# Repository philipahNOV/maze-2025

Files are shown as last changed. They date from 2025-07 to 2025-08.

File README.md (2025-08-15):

# Autonomous Maze Solver - NOV 2025

This project is an autonomous maze-solving system that uses computer vision and robotics to guide a steel ball through physical mazes. The system tilts a maze board with two motors to navigate the ball from start to goal while avoiding holes and obstacles.

The core architecture consists of three main devices: a Jetson Orin Nano for computer vision and control logic, a Raspberry Pi for the human-machine interface, and an Arduino for motor control. A ZED 2i stereo camera mounted above the maze provides real-time ball tracking using a TensorRT-optimized YOLOv8 model. The system calculates optimal paths with A* pathfinding and executes precise movements through PID control.

Users can choose between autonomous mode where the system solves the maze automatically, manual mode for joystick control with competitive timing, and human vs AI mode for head-to-head competition. A local leaderboard tracks the fastest completion times across different maze configurations.

Most system parameters are configured through `config.yaml`, making it easy to adapt to different maze layouts, adjust control parameters, and modify tracking settings without code changes.

---

## Table of Contents

- [System Overview](#system-overview)  
- [Physical Setup](#physical-setup)
- [Setup & Configuration](#setup--configuration)
  - [Login Information](#login--information)
  - [Dependencies](#dependencies)
- [Control System](#control-system)
  - [System Components](#system-components)
  - [Control Execution Flow](#control-execution-flow)
  - [Controller Configuration](#controller-configuration)
  - [Path Execution](#path-execution)
  - [Horizontal Calibration](#horizontal-calibration)
  - [MQTT Command Integration](#mqtt-command-integration)
  - [Troubleshooting](#troubleshooting)
  - [Tuning Tips](#tuning-tips)
  - [Electrical Setup](#electrical-setup)
- [MQTT Communication](#mqtt-communication)
  - [Overview](#overview)
  - [Topic Structure](#topic-structure)
  - [Handshake Protocol](#handshake-protocol)
  - [Jetson MQTT Client](#jetson-mqtt-client)
  - [Pi MQTT Client](#pi-mqtt-client)
  - [MQTT Troubleshooting](#mqtt-troubleshooting)
- [Ball Detection](#ball-detection)
  - [System Architecture](#ball-detection-architecture)
  - [Camera Acquisition](#camera-acquisition)
  - [TensorRT YOLO Inference](#tensorrt-yolo-inference)
  - [Ball Tracking](#ball-tracking)
  - [Tracker Service](#tracker-service)
  - [Detection Troubleshooting](#detection-troubleshooting)
- [A* Pathfinding](#a-pathfinding)
  - [A* Algorithm with Repulsion Field](#a-algorithm-with-repulsion-field)
  - [Binary Mask Preprocessing](#binary-mask-preprocessing)
  - [Waypoint Sampling](#waypoint-sampling)
  - [Path Drawing](#path-drawing)
  - [Path Memory Caching](#path-memory-caching)
  - [Nearest Walkable Point](#nearest-walkable-point)
  - [Pathfinding Troubleshooting](#pathfinding-troubleshooting)
- [Authors](#authors)

---

## System Overview

### Core Architecture
- **Jetson Orin Nano**: Primary control unit running TensorRT-optimized YOLOv8 inference, A* pathfinding, and PID control logic
- **Raspberry Pi**: Touchscreen HMI providing user interaction, mode selection, and real-time system status
- **Arduino Mega**: Motor controller executing precise tilt commands via dual-axis PID control
- **ZED 2i Camera**: Stereo camera providing real-time ball position tracking and maze orientation detection

### Software Components
- **Ball Detection**: TensorRT-accelerated YOLOv8 model with boundary validation and position smoothing
- **Path Planning**: A* algorithm with repulsion fields and optimized waypoint sampling
- **Control System**: PID-based position control with adaptive lookahead and error correction
- **Communication**: MQTT-based messaging between all system components
- **User Interface**: Multi-mode touchscreen interface with competitive leaderboards

### Operating Modes
- **Navigation Mode**: Automatic maze solving with real-time path visualization
- **Practice Mode**: Manual joystick control for practicing with a joystick
- **Play Alone**: Timed single-player challenges with leaderboard integration
- **Human vs Robot**: Competitive mode alternating between human and robot turns
- **Admin Tools**: Calibration, and access to shutdown and other tools

---

## Physical Setup

### Transport Configuration
Before operation, disconnect the transport rod by unscrewing with a 3mm hex key, then reinstall the screw at the bottom position.

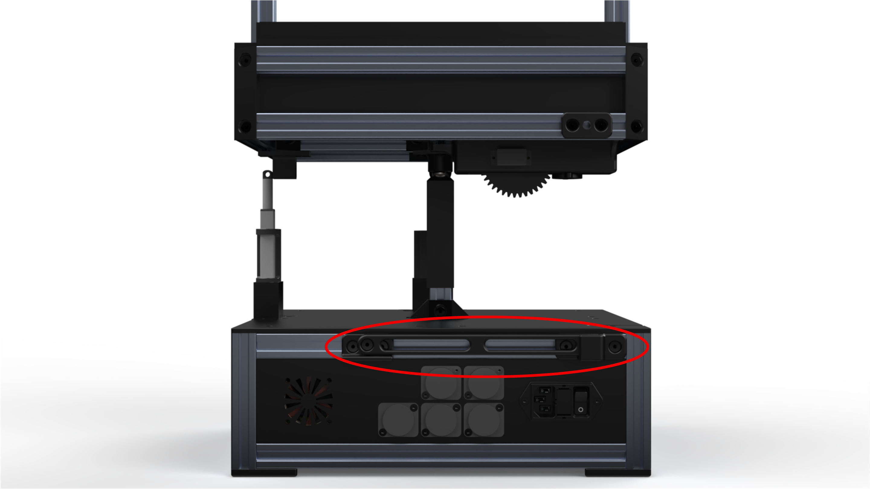
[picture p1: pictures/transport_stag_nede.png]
Transport Rod Up


For transportation, move the transport rod to the upper position to secure the platform.

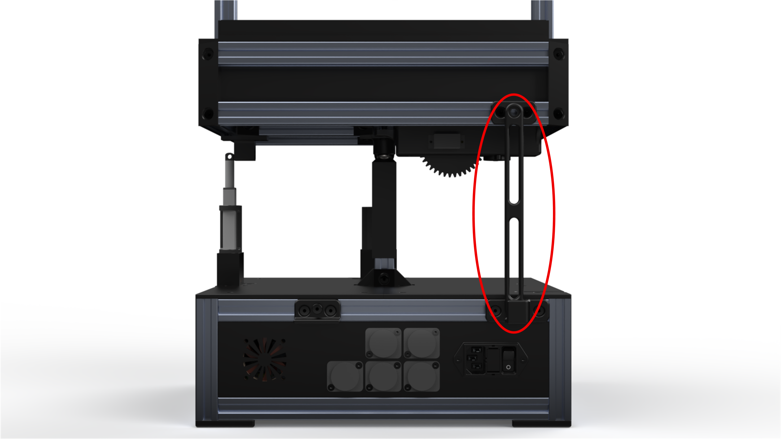
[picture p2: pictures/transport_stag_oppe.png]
Transport Rod Down


### Access Panels
Use a 2mm hex key to remove the electronics panel covers for maintenance access.

### Camera Positioning
Mount the ZED 2i camera directly above the maze center with clear line-of-sight to the entire playing surface.

---

## Setup & Configuration

### Login Information

**Raspberry Pi:**
- Username: raspberrypi
- Password: raspberry

**Jetson:**
- Username: student
- Password: student

### Dependencies

Install all required packages via requirements file:

```bash
pip install -r requirements.txt
```
---

## Flow of the FSM

The system operates through a well-defined state machine `finite_state_machine.py` with the following states:

### BOOTING
Initial state. Transitions to `MAIN_SCREEN` after the Raspberry Pi and Jetson perform a MQTT handshake.

### MAIN_SCREEN
Functions as a home-screen. May branch into several states.

### ADMIN_TOOLS
Requires a code to enter. From here, the admin can calibrate, clear leaderboards and path cache, restart, reboot or shutdown the robot.

### INFO_SCREEN
Displays information about the project.

### LOCATING
Transitioned into from `MAIN_SCREEN` when autonomous solving is chosen. Starts tracker and other threads required to locate the ball. When the ball is found, the state transitions to `CUSTOM_PATH`. 

### CUSTOM_PATH
In this state/screen, the user can choose a path goal by touching an image of the maze. By pressing 'Calculate path', finding a path will be attempted. If a path is found, start-buttons are enabled. The user can choose 'safe-control' or 'fast-control', which are two modes of the controller. When one of the buttons is pressed, the state transitions into `CONTROLLING`

### CONTROLLING
In this state, the control loop is running, letting the robot autonomously balance the ball through the maze. On the screen, a large live camera feed of the maze is displayed for the user to examin while executing. 

### HUMAN_CONTROLLER
Transitioned into from `MAIN_SCREEN` if the user chooses 'Game modes'. The main property of this state and states branching from it, is that the user may control the maze using and Xbox controller.

### PRACTICE
Playground for the user to attempt the maze without being able to loose and without being timed by a stop-watch.

### PLAYALONE
Start of the sequence of states that let the player attempt the maze while having their time recorded and, if succeeding, added to the leaderboard. In this state, the user may enter their name on the screen. Transitions into `PLAYALONE_START` when the user confirms their name

### PLAYALONE_START
In this state, the ball is continuously tracked. If the ball is located withing the elevator, the user may start their attempt. After pressing start, the user attempt is began, letting the user control the ball using the Xbox controller. If the ball falls through a hole, the state transitions into `PLAYALONE_FAILED`. If the ball reaches the goal, the state transitions into `PLAYALONE VICTORY`.

### PLAYALONE_FAILED
State where the user may either exit from the game mode, or choose to try again, returning to `PLAYALONE_START`

### PLAYALONE_VICTORY
The users maze solving time is saved. Their rank is computed by comparing the time to the leaderboard of the corresponding maze. The maze type (easy or hard) is automatically determined by the camera. The users time is added to the leaderboard.

### LEADERBOARD
Transitioned into using the corresponding button in either `HUMAN_CONTROLLER` or `PLAYALONE_VICTORY`. Displays the leaderboards of the easy and hard maze. The user may use a button to swap between the two displays.

### PLAYVSAI
Start of the sequence for the game mode 'Human vs Robot'. In this state, the user may choose a goal by touching an image of the maze. Then the user may press 'Start robot'.

### PLAYVSAI_PID
Transitioned into when the user presses 'Start robot' in `PLAYVSAI`. The robot computes a path to the goal, and attempts to balance the ball through it. If success, the time is saved.

### PLAYVSAI_HUMAN
Transitioned into after the robot has either failed or succeeded in `PLAYVSAI_PID`. The user may press 'Start turn' and then control the ball through the maze using the xBox controller. If success, the time is saved. The times of the robot and the user are compared, and the winner is determined. 

### **Sate transition logic**
Each state handles specific commands and maintains system integrity:
- **Back Commands**: Clean state transitions with resource cleanup
- **Error Handling**: Automatic fallback to safe states on failures
- **Resource Management**: Thread lifecycle and hardware control coordination

### **MQTT Command integration**

The control system integrates tightly with MQTT communication for coordinated operation:

**Command Processing**: The finite state machine subscribes to `jetson/command` topic and processes:
- Mode transitions (Practice, PlayAlone, Navigate, etc.)
- Game controls (StartGame, Retry, Back)
- System commands (Locate, AdminTools, Disco)

**Status Broadcasting**: Control states are published to relevant topics:
- `pi/command`: UI state updates and game results
- `pi/tracking_status`: Ball detection status and game events
- `arduino/speed`: Real-time motor control commands

## Control System

### System Components

The control system integrates multiple subsystems through a centralized finite state machine:

**Position Controller** (`position_controller.py`): 
- `posControl`: PID-based control system computing tilt angles in both X and Y axis required for the ball to reach the target waypoint.
- `axisControl`: P-controller that takes in reference tilt angles from the position controller, computes motor velocities, and sends the velocities to the Arduino

**Arduino Connection** (`arduino_connection.py`): Serial communication interface handling motor commands, elevator control, and system status feedback.

**Joystick Controller**: Manual control interface for practice mode and human vs AI gameplay.

### Controller Configuration

The PID controller accepts configuration through `config.yaml`:

```yaml
position_controller_normal:
    feedforward_t: 7.8
    kd_x: 0.000085
    kd_y: 0.000085
    ki_x: 0.0004
    ki_y: 0.0004
    kp_x: 0.00004
    kp_y: 0.00004
    position_tolerance: 25
    velocity_tolerance: 20
  position_smoothing_alpha: 0.1
  stuck_time_threshold: 0.5
  stuck_unstuck_hold_time: 0.2
  stuck_upper_position_threshold: 70
  stuck_velocity_threshold: 30
  stuck_wiggle_amplitude: 0.4
  stuck_wiggle_frequency: 20
  velocity_smoothing_alpha: 0.99
  wiggle_direction_bias: 0.007
```

**Key Parameters:**
- **feedforward_t**: Tuning parameter for feedforward. Increasing this reduces the responsiveness of the system. Decreasing may lead to fast but unstable responses.
- **kp**: Proportional gain. Increase to punish position error deviations.
- **ki**: Integral gain. Increase to punish position error deviations over time. Prevents steady-state errors.
- **kd**: Derivative gain. Increase for more damping. Increase to punish large velocities and to 'break' when approaching waypoints.
- **position_tolerance**: Acceptance radius for waypoint navigation.

### Path Execution

Path execution occurs in the `run_controller_main.main()` function with the following sequence:

1. **Path Validation**: Verify path waypoints are within maze boundaries
2. **Target Assignment**: Set initial target to first path waypoint
3. **Position Control Loop**:
   - Get current ball position from tracking service
   - Calculate PID control output for X/Y axes
   - Apply velocity limits and send motor commands
   - Check target proximity and advance to next waypoint
4. **Completion Detection**: Monitor goal proximity and handle success/failure states

### Path-following scheme
The controller may use one of two path-following schemes. Both schemes have advantages and dissadvantages, and the user may choose what scheme to use when starting the control execution after path-finding.
The member variable `lookahead` in `position_controller.py` can be set to `True` or `False` corresponding to waypoint navigation and pure pursuit respectively. This should be set before starting `run_controller_main.py`.

**Waypoint Navigation**

*In the HMI, this is referred to as "Safe Control"*
- Setpoint control toward the next waypoint
- Advances waypoint when the ball is within an acceptance radius
- Uses dwell/advance logic at each waypoint. This ensures the ball rests at waypoints and helps prevent prematurely turning around corners.
- Timeout based waypoint reverting. When a certain amount of time passes with no waypoint advancements, the target waypoint is reverted to the previous in the path.
- Pros:
    - Accurately controls to each waypoint
    - Ball velocity stays controllable
- Cons:
    - The scheme is optimal when the path consists of few waypoints. This large reduction with waypoint sampling may lead to important waypoints being removed, resulting in a bad path.
    - Slow. Stops at every waypoint.
    - Low velocities may result in the ball stopping just before a waypoint, then advancing. This leads to cutting of turns. This is attempted prevented using dwell/advance.

**Pure Pursuit**

*In the HMI, this is referred to as "Fast Control"*
- Projects the ball onto the nearest segment between two waypoints. Then walks along the path from the projected point a total distance of `lookahead distance`. The resulting point is chosen as the target reference for position control.
- The projection is continuous, resulting in a smoother path trajectory.
- Pros:
    - Continuous path following
    - Fast control due to not stopping at waypoints
    - Smooth path/turns
    - Natural ball movement
    - Does not rely on optimal waypoint sampling
- Cons:
    - Smaller reduction of waypoints through sampling. This results in a more computaionally expensive control loop.
    - Cuts turns due to the lookahead.
    - Velocity may build up enough to become difficult to stop quickly using damping.

### Horizontal Calibration

The system includes automatic horizontal calibration to establish a neutral maze position.
Calibration occurs automatically during state transitions and can be manually triggered through the admin interface.

### Tuning Tips

- Use current values as a base line
- More responsiveness -> Increase `feedforward_t`
- Smaller max velocities -> Increase `k_d`
- More accurately stopping at waypoints -> Increase `k_d`
- Prevent ball from getting stuck close to waypoints -> Increase `k_i`
- Improve path accuracy (waypoint navigation) -> Decrease `position_tolerance`
    - Consequence: Results in ball stopping more often and struggling to approach waypoint.
- Improve path accuracy (pure pursuit) -> Decrease `lookahead_distance`
    - Consequence: Reacts more slowly to path turns. Less predictive behaviour.

## Electrical Setup

This subsystem delivers power, feedback, actuation and data links between Jetson, Raspberry Pi, Arduino, motors and the user interface.

### Power Architecture
- Primary PSU:
    - Mean Well 85 W dual-output (5 V & 12 V)
- 5 V rail:
    - Raspberry Pi 5
    - LCD touch display
    - Elevator servo
    - LEDs
- 12 V rail:
    - NVIDIA Jetson Orin Nano
    - Motor controller
    - Enclosure cooling fan
- Arduino Mega:
    - Powered via USB from Jetson

### Arduino Interfaces
- 5 V out (Arduino) → Positive reference for actuators potentiometers
- Position feedback (linear actuator pots):
  - Motor 1: A4
  - Motor 2: A3
  - Approximate ADC span: ~2 (fully retracted) to ~1018 at 50 mm extension
- Motor PWM (direction-specific lines):
  - Motor 1 Up: D9
  - Motor 1 Down: D10
  - Motor 2 Up: D11
  - Motor 2 Down: D12
  (Only one direction pin per motor should be active at a time)
- Elevator servo: D5
- LEDs: D7

### Communication Wiring
- Jetson ↔ Arduino: USB serial (motor commands, servo, LEDs)
- Jetson ↔ Raspberry Pi: Ethernet (primary), MQTT over Wi‑Fi as fallback
- Arduino ↔ Motor Controller: PWM (D9–D12) + analog feedback (A4, A3)
- Touch screen (video): HDMI via pass‑through (switchable Pi / Jetson)
- Touch screen (touch interface): USB‑A (normally to Pi, movable to Jetson)

### Pass-Through Panel (Rear)
External I/O without opening the enclosure:
- 2 × USB‑A
- 2 × HDMI
- 1 × USB‑C (5 V power out)

Panel mapping:
- Lower USB‑A + lower HDMI → Raspberry Pi 5
- Lower USB‑C → 5 V (screen power)
- Upper USB‑A + upper HDMI → Jetson Orin Nano

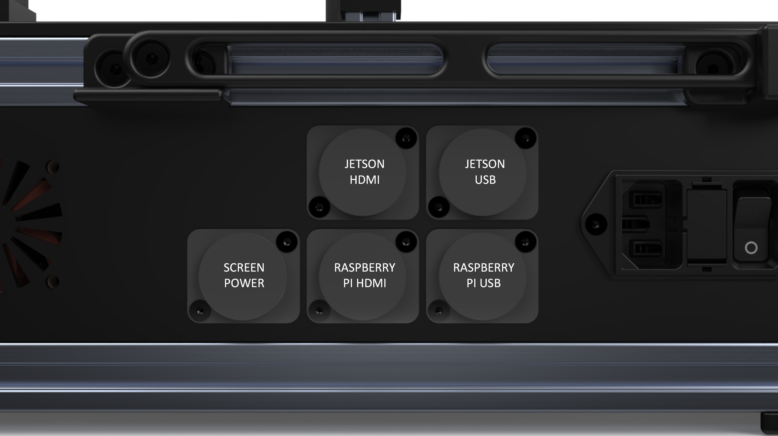
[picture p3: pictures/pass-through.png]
Pass-through Photo


### Touch Screen Usage
- Power: USB‑C cable
- Touch: USB‑A cable
- Normal mode: HDMI + USB‑A routed to Raspberry Pi
- Switch to Jetson: Move HDMI (and optionally touch USB) to Jetson-linked pass‑through ports

### Electrical Schematic
Schematic

### Fuses
- Power entry module: 3.15 A ceramic cartridge
- Each motor: 2 A glass cartridge
- Spares: Both types stored in the transport box

---

## MQTT Communication

### Overview

The system uses MQTT as the primary communication protocol between the Jetson control unit and Raspberry Pi interface. This lightweight publish-subscribe protocol gives a reliable message delivery with low latency.

Raspberry Pi IP: `192.168.1.2`

Jetson IP: `192.168.1.3`

The broker runs locally on the Jetson device.

### Topic Structure

The topic hierarchy follows a device-based naming convention for clear message routing:

#### **Jetson Publishes:**
- `handshake/response`: Handshake response to Pi.
- `pi/command`: General commands.
- `pi/camera`: Camera feed.
- `pi/info`: General information flow from Jetson to Pi.
- `pi/tracking_status`: Information about wether the tracker is started and wether or not the ball is found.
- `pi/leaderboard_data`: Sending of leaderboard data. 

#### **Pi publishes:**
- `hadshake/request`: Initiate handshake process.
- `jetson/command`: General commands to transition states in the FSM.
- `jetson/player_name`: Information about player name when using joystick.

### Handshake Protocol

Device initialization follows a structured handshake sequence to ensure reliable connection establishment:

1. **Pi Startup**: Publishes connection request to `jetson/handshake`
2. **Jetson Response**: Acknowledges connection and sends initial state
3. **State Synchronization**: Exchange current system mode and configuration
4. **Heartbeat Establishment**: Begin periodic status updates

### Jetson MQTT Client

The Jetson MQTT client (`MQTTClientJetson`) manages all communication from the control system:

```python
class MQTTClientJetson(threading.Thread):
    def __init__(self, arduino_connection: ArduinoConnection = None, fsm = None, broker_address="192.168.1.3", port=1883):
        super().__init__()
        self.client = mqtt.Client(mqtt.CallbackAPIVersion.VERSION2)  # type: ignore
        self.client.on_connect = self.on_connect
        self.client.on_message = self.on_message
        self.client.on_disconnect = self.on_disconnect

    def on_message(self, client, userdata, msg):
        payload = msg.payload.decode()
        topic = msg.topic
        print(f"Message received on topic '{topic}': {payload}")

        if topic == "handshake/request":
            if payload == "pi":
                self.client.publish("handshake/response", "ack", qos=1)
                self.client.publish("pi/command", "booted", qos=1)
                self.handshake_complete = True
```
### Pi MQTT Client

The Pi MQTT client handles the touchscreen interface and user interaction:

```python
class MQTTClientPi(threading.Thread):
    def __init__(self, broker_address='192.168.1.3', port=1883):
        super().__init__()
        self.client = mqtt.Client(mqtt.CallbackAPIVersion.VERSION2)
        self.client.on_connect = self.on_connect
        self.client.on_message = self.on_message
        
    def on_message(self, client, userdata, msg):
        if msg.topic == "pi/command":
            payload = msg.payload.decode()
            if payload.startswith("playalone_success:"):
                duration = payload.split(":")[1]
                rank = payload.split(":")[2]
                if self.app and hasattr(self.app, 'frames'):
```

### MQTT Troubleshooting

**Connection Issues:**
- Verify broker is running: `sudo systemctl status mosquitto`
- Check connectivity between devices
- Monitor broker logs: `sudo tail -f /var/log/mosquitto/mosquitto.log`

---

## Ball Detection

### System Architecture

The ball detection system uses a TensorRT-optimized YOLOv8 model for robust real-time ball tracking. The detection pipeline operates at 50 FPS with the following components:
- **Camera Manager**: ZED 2i stereo camera interface with hardware-accelerated frame capture
- **YOLO Model**: TensorRT-optimized object detection with CUDA context management
- **Ball Tracker**: Producer-consumer threading with boundary validation and position smoothing
- **Tracker Service**: High-level coordination and state management

### Camera Acquisition

The `CameraManager` class handles ZED 2i camera initialization and frame acquisition:

```python
CLASS CameraManager:
    INIT():
        Create ZED camera object
        Mark as not initialized

    FUNCTION init_camera():
        IF already initialized:
            RETURN
        Create camera initialization parameters:
            - Resolution: HD720
            - FPS: 60
            - Depth mode: Neural
            - Units: Millimeters
        TRY to open ZED camera with parameters
        IF open fails:
            RAISE error "Camera failed to open"
        Mark as initialized

    FUNCTION grab_frame():
        Create empty image container
        IF ZED grab() succeeds:
            Retrieve LEFT view image into container
            Convert image to BGR format
            Convert BGR to RGB format
            RETURN (rgb_frame, bgr_frame)
        ELSE:
            RETURN (None, None)

    FUNCTION get_orientation():
        Create sensor data container
        IF retrieving sensor data fails:
            RETURN None
        Get IMU data from sensor data
        Create transform container
        Get orientation quaternion from IMU pose
        Round quaternion values to 3 decimal places
        Calculate:
            dir1 = ox + ow
            dir2 = oy - oz
        RETURN orientation vector [-dir2, dir1]

    FUNCTION close():
        IF camera is initialized:
            Close ZED camera
            Mark as not initialized
```

### TensorRT YOLO Inference

The `YOLOModel` class implements optimized inference with TensorRT acceleration:

```python
CLASS YOLOModel:
    INIT(model_path, input_shape, conf):
        Store input shape and confidence threshold
        Initialize variables and lock
        TRY:
            Initialize TensorRT engine (preferred)
            Set engine_type = "tensorrt"
        EXCEPT:
            Print warning and fall back to PyTorch
            Set engine_type = "pytorch"

    FUNCTION _init_tensorrt(model_path):
        Initialize CUDA context
        Create TensorRT runtime
        Load engine from file
        Create execution context
        Get input/output bindings and data types
        Allocate host and device memory
        Create CUDA stream

    FUNCTION _init_pytorch_fallback(model_path):
        Convert engine path to .pt file path
        Load YOLO model from PyTorch
        Detect available device (GPU/CPU)
        Set class names from model

    DESTRUCTOR:
        If CUDA context exists, pop it

    FUNCTION get_label(cls_id):
        RETURN class name from ID

    FUNCTION preprocess(image):
        Resize image to model input size
        Normalize pixel values to [0,1]
        Rearrange channels (CHW)
        Convert to float16
        Copy into host input buffer

    FUNCTION predict(image):
        IF engine_type == "tensorrt":
            RETURN _predict_tensorrt(image)
        ELSE:
            RETURN _predict_pytorch(image)

    FUNCTION _predict_tensorrt(image) [ensured CUDA context]:
        Store original image dimensions
        Preprocess image
        Copy input data to GPU
        Execute inference asynchronously
        Copy output data from GPU
        Synchronize stream
        Postprocess and return results

    FUNCTION _predict_pytorch(image):
        Run PyTorch YOLO inference
        Return the first result object

    FUNCTION postprocess(output):
        If output shape is invalid → return empty result
        Filter detections by confidence threshold
        Convert normalized coords to original image coords
        Run Non-Maximum Suppression (NMS)
        Select best detection
        RETURN Result object with Box data

    FUNCTION nms(boxes, scores, iou_threshold):
        Sort boxes by score (descending)
        Iteratively keep highest-scoring boxes that don't overlap too much
        RETURN kept box indices

    FUNCTION _empty_result():
        RETURN object with empty boxes list

    FUNCTION shutdown():
        Acquire lock
        If already shutdown → return
        Mark as shutdown
        Free GPU memory
        Delete TensorRT resources
        Pop CUDA context if still active
        Print shutdown complete

CLASS Box:
    INIT(x1, y1, x2, y2, conf, cls):
        Store coordinates in xyxy format
        Store confidence and class
        Compute xywh format

CLASS Result:
    INIT(boxes):
        Store list of Box objects
```

**Performance Benefits:**
- **Fast**: TensorRT optimization significantly reduces inference time
- **Memory**: Optimized memory allocation and reuse
- **Latency**: Predictable inference times for real-time control
- **Fallback**: Automatic PyTorch fallback if TensorRT unavailable

### Ball Tracking

The `BallTracker` class implements a producer-consumer pattern for continuous ball tracking:

```python
CLASS BallTracker:
    INIT(camera, tracking_config, model_path):
        Load YOLO model from model_path
        Store camera reference
        Set configuration parameters (or defaults)
        Initialize runtime variables:
            - running state
            - initialized state
            - frame queue (small size buffer)
            - latest BGR frame
            - current ball position
            - bounding box buffer
            - maze boundaries (top-left, top-right, bottom-left, bottom-right)
    
    FUNCTION is_point_in_maze(x, y):
        RETURN True if point is inside maze bounds
    
    FUNCTION producer_loop():
        WHILE running:
            Record start time
            Capture RGB and BGR frames from camera
            IF frames are valid:
                Add frames to queue
            Sleep to maintain ~60 FPS

    FUNCTION consumer_loop():
        WHILE running:
            IF no frames in queue:
                Short sleep
                CONTINUE
            Remove older frames so only latest remains
            Take most recent RGB and BGR frames
            Store latest BGR for later retrieval

            Run YOLO inference on RGB frame
            Clear current ball position

            Filter predicted boxes for label "ball" (max 1)
            FOR each detected ball:
                Compute center coordinates
                IF ball center is inside maze:
                    Save ball position
                    Normalize coordinates relative to frame size
                    Update bounding box buffer
                    BREAK (only first ball used)

            Sleep to maintain ~50 FPS

    FUNCTION start():
        Set running = True and initialized = True
        Start producer thread (frame grabbing)
        Start consumer thread (detection/tracking)

    FUNCTION stop():
        Set running = False
        Set initialized = False
        IF model has shutdown method:
            Call shutdown

    FUNCTION get_position():
        RETURN current ball position

    FUNCTION get_frame():
        RETURN latest BGR frame (if available)

    FUNCTION retrack():
        Reset ball position
```

**Key Features:**
- **Threading**: Separate detection thread prevents blocking the control loop
- **Boundary Validation**: Rejects detections outside valid maze area
- **Position Smoothing**: Exponential moving average reduces noise
- **Thread Safety**: Proper locking for concurrent position access

### Tracker Service

The `TrackerService` provides a high-level interface for the tracking system:

```python
CLASS TrackerService:
    INIT(model_path, tracking_config):
        Create CameraManager instance
        Initialize camera
        Set tracker to None
        Mark as not started
        Store model path
        Store tracking config (or default)

    FUNCTION start_tracker():
        IF already started:
            RETURN
        Create BallTracker instance (pass camera, config, model_path)
        Start BallTracker threads (producer & consumer)
        Mark as started

    FUNCTION stop_tracker():
        IF started:
            Stop BallTracker
            Mark as not started

    FUNCTION get_ball_position():
        IF started:
            RETURN ball position from tracker
        ELSE:
            RETURN None

    FUNCTION get_stable_frame():
        IF started:
            RETURN latest BGR frame from tracker
        ELSE:
            RETURN None

    FUNCTION get_orientation():
        RETURN orientation vector from camera IMU

    PROPERTY is_initialized:
        RETURN tracker.initialized if tracker exists, else False

    FUNCTION retrack():
        IF started AND tracker exists:
            Call retrack() on BallTracker
```

### Detection Troubleshooting

**Common Issues and Solutions:**

**Ball Detection Failures:**
- Check lighting conditions, even illumination without shadows is ideal
- Verify camera focus and positioning for clear ball visibility
- Check GPU memory usage as insufficient VRAM can cause inference failures

**Position Accuracy Problems:**
- Calibrate the maze
- Check camera mounting stability

---

## A* Pathfinding

### A* Algorithm with Repulsion Field

The pathfinding system uses an enhanced A* algorithm with repulsion fields to generate safe, efficient paths through the maze. Unlike standard A*, this implementation adds artificial potential fields around obstacles to create paths that maintain safe distances from walls and holes.

#### **Heuristic Function**
The heuristic uses Manhattan distance:

```python
FUNCTION heuristic(a, b):
    RETURN Manhattan distance between a and b
    # (Alternatively: Euclidean distance for fewer node expansions)
```

#### **Repulsion Map Generation**
Repulsion fields are precomputed using distance transforms, in order to not make the path hug the walls:

```python
FUNCTION compute_repulsion_cost(array, min_safe_dist):
    Compute distance transform of obstacle map
    Create mask marking cells >= min_safe_dist as walkable
    Find maximum distance value
    IF max distance is zero:
        RETURN ones array (no repulsion), mask
    ELSE:
        Compute repulsion cost as (1 - (dist / max_dist))^3
        RETURN repulsion cost map, mask
```

#### **Path Search Implementation**
The core A* search integrates repulsion costs:

```python
FUNCTION astar(array, start, goal, repulsion_weight):
    rows, cols = dimensions of array
    repulsion_map, walkable_mask = compute_repulsion_cost(array)

    Define neighbor offsets (up, down, left, right)

    Create min-heap for open set
    Push start node with f = g + h

    Initialize:
        came_from = empty dict
        g_score = array filled with infinity
        g_score[start] = 0
        in_open = set containing start
        closed = boolean array (all False)

    WHILE open_heap not empty:
        Pop node with lowest fscore
        Remove from in_open

        IF current node == goal:
            Reconstruct path by backtracking via came_from
            RETURN path (start → goal)

        Mark current as closed

        FOR each neighbor offset (dx, dy):
            nx, ny = current.x + dx, current.y + dy

            IF neighbor out of bounds → skip
            IF not walkable or already closed → skip

            move_cost = 1 + repulsion_weight * repulsion_map[nx, ny]
            tentative_g = cost_so_far + move_cost

            IF tentative_g < g_score[neighbor]:
                Update came_from[neighbor] = current
                g_score[neighbor] = tentative_g
                fscore = tentative_g + heuristic(neighbor, goal)
                IF neighbor not in in_open:
                    Push (fscore, tentative_g, neighbor) to heap
                    Add neighbor to in_open

    RETURN empty list (no path found)
```

### Binary Mask Preprocessing

High-quality binary masks separating clear areas for the ball and the walls/holes are important for reliable pathfinding:

#### **Dilation and CLAHE**
```python
FUNCTION dilate_mask(mask, kernel_size, iterations):
    Create kernel of ones (uint8) with given size
    RETURN result of morphological dilation on mask using kernel for given iterations

FUNCTION get_dynamic_threshold(image, target_brightness):
    Convert image to grayscale
    Compute current average brightness
    Calculate adjustment = target_brightness - current_brightness
    Adjust grayscale pixel values by this amount (clip to range 0–255)
    RETURN adjusted grayscale image

FUNCTION apply_clahe(gray):
    Create CLAHE object (contrast-limited adaptive histogram equalization)
    Apply CLAHE to grayscale image
    RETURN enhanced grayscale image
```

#### **Edge Removal and Morphology**
```python
FUNCTION create_binary_mask(gray):
    enhanced = apply_clahe(gray)
    base_mask = Otsu binary threshold on enhanced image
    cleaned = Morphological closing (kernel 5x5) on base_mask, 2 iterations

    edges = Canny edge detection on enhanced image (thresholds 100, 200)
    edges_dilated = Dilate edges with 3x3 kernel, 1 iteration
    edges_inv = Invert edges_dilated

    final_mask = Logical AND between cleaned mask and edges_inv
    final_mask = Morphological closing (kernel 7x7) on final_mask, 1 iteration

    RETURN final_mask
```

### Waypoint Sampling

The waypoint sampling system transforms raw A* paths into optimized trajectories suitable for physical ball control. The process combines multiple geometric algorithms to balance path smoothness, control accuracy, and computational efficiency.

#### **Theoretical Foundation**

The system uses a multi-stage optimization pipeline:

1. **Raw path densification**: Continuous coverage along path segments by adding intermediate points at regular intervals
2. **Direction change**: Identifies course changes requiring explicit waypoints for accurate navigation
3. **L-Pivot smoothing**: Inserts intermediate waypoints at corners to for 90 degrees turns
4. **Douglas-Peucker**: Reduces redundant waypoints while preserving path geometry within specified tolerance
5. **Statistical refinement**: Segment length analysis to maintain consistent waypoint spacing

#### **Implementation**

The sampling algorithm processes raw A* output through several transformation stages:

```python
FUNCTION sample_waypoints(path, mask):
    raw = [first point in path]
    y, x = first point
    FOR each (ty, tx) in remaining path points:
        dx = tx - x
        sx = 1 if tx > x else -1
        FOR xx from x+sx to tx (inclusive) step sx:
            IF mask[y][xx] is walkable:
                append (y, xx) to raw
        x = tx

        dy = ty - y
        sy = 1 if ty > y else -1
        FOR yy from y+sy to ty (inclusive) step sy:
            IF mask[yy][x] is walkable:
                append (yy, x) to raw
        y = ty

    pts = [raw[0]]
    FOR (prev, curr, nxt) sliding through raw:
        dir1 = vector from prev → curr
        dir2 = vector from curr → nxt
        IF direction changes:
            append curr to pts
    append last point of raw to pts

    full = [pts[0]]
    FOR (a, b, c) sliding through pts:
        IF straight in one axis but corner in next:
            Generate intermediate corner points:
                (a.y, c.x), (c.y, c.x)
            IF not duplicate AND clear_path from last full point to new point:
                append new point to full
        IF b not already last in full:
            append b
    Append last point of pts if missing

    seg_dists = distances between consecutive points in full
    mean_seg = average segment length
    eps = mean_seg * log(raw_length + 1)
    waypoints = Douglas-Peucker simplify(full, eps)

    IF at least two waypoints:
        Compute average and std deviation of segment lengths
        threshold = avg + std
        new_wps = [first waypoint]
        FOR each segment (a, b):
            IF length > threshold:
                mid = midpoint between a and b
                append mid
            append b
        waypoints = new_wps

    RETURN waypoints

```

#### **Douglas-Peucker Algorithm**

The system uses the Douglas-Peucker algorithm for path simplification:

```python
FUNCTION _douglas_peucker(pts, eps):
    IF fewer than 3 points:
        RETURN pts

    a = first point in pts
    b = last point in pts
    idx = 0
    dmax = 0.0

    FOR i from 1 to len(pts)-2:
        d = _perp_dist(pts[i], a, b)
        IF d > dmax:
            idx = i
            dmax = d

    IF dmax <= eps:
        RETURN [a, b]  # all points lie close to straight line

    left = _douglas_peucker(points from a to pts[idx], eps)
    right = _douglas_peucker(points from pts[idx] to b, eps)

    RETURN left[:-1] + right

FUNCTION _perp_dist(pt, a, b):
    y0, x0 = pt
    y1, x1 = a
    y2, x2 = b

    num = ABS((x1 - x0) * (y2 - y0) - (x2 - x0) * (y1 - y0))
    den = Euclidean distance between a and b (avoid division by zero)
    RETURN num / den

```

### Path Drawing

Visual path representation for debugging and user feedback:

```python
FUNCTION draw_path(image, waypoints, start, goal):
    out = copy of image

    IF image is grayscale (2D) or has 1 channel:
        Convert to BGR
    ELSE IF image has 4 channels (BGRA):
        Convert to BGR

    h, w = image height and width

    FOR each (x, y) in waypoints (if any):
        IF y within [0, h) AND x within [0, w):
            Draw filled circle at (x, y) with radius 4 and color (128, 0, 0)  # dark red

    IF start exists:
        Draw filled green circle (0, 255, 0) at (start col, start row), radius 5
    IF goal exists:
        Draw filled blue circle (255, 0, 0) at (goal col, goal row), radius 5

    RETURN out

```

### Path Memory Caching

Caching reduces computation for repeated queries, skipping the A* loading time:

```python
FUNCTION get_cached_path(start, goal):
    FOR each entry in self.paths:
        s = entry["start"]
        g = entry["goal"]
        path = entry["path"]
        IF start is within tolerance of s AND goal is within tolerance of g:
            RETURN path
    RETURN None

FUNCTION cache_path(start, goal, path):
    IF number of cached paths >= max_paths:
        Remove the oldest entry from self.paths

    Append to self.paths:
        {
            "start": start as list,
            "goal": goal as list,
            "path": each point in path as list
        }

    Call self.save_cache()
```

### Nearest Walkable Point

Handles cases where start/goal points are in invalid areas:

```python
FUNCTION find_nearest_walkable(mask, point, max_radius):
    y, x = point

    IF mask[y, x] != 0:
        RETURN point

    dist = DistanceTransform of mask (L2 metric, kernel size 5)

    min_val = infinity
    nearest = point
    h, w = mask dimensions

    FOR dy from -max_radius to max_radius:
        FOR dx from -max_radius to max_radius:
            ny = y + dy
            nx = x + dx

            IF ny, nx inside mask bounds AND mask[ny, nx] > 0:
                IF dist[ny, nx] < min_val:
                    min_val = dist[ny, nx]
                    nearest = (ny, nx)

    RETURN nearest
```

### Pathfinding Troubleshooting

#### **repulsion_weight**
Controls how strongly paths avoid obstacles:
- **Too Low (<5)**: Paths may pass too close to walls, risking collisions
- **Too High (>20)**: Paths become overly conservative and inefficient
- **Optimal Range**: 8-15 for most maze configurations

#### **min_safe_dist in repulsion**  
Minimum distance maintained from obstacles:
- **Too Small (<10 pixels)**: Insufficient safety margin for control errors
- **Too Large (>30 pixels)**: May make narrow passages impassable
- **Recommended**: 15-25 pixels based on ball size and control precision

---

## Authors

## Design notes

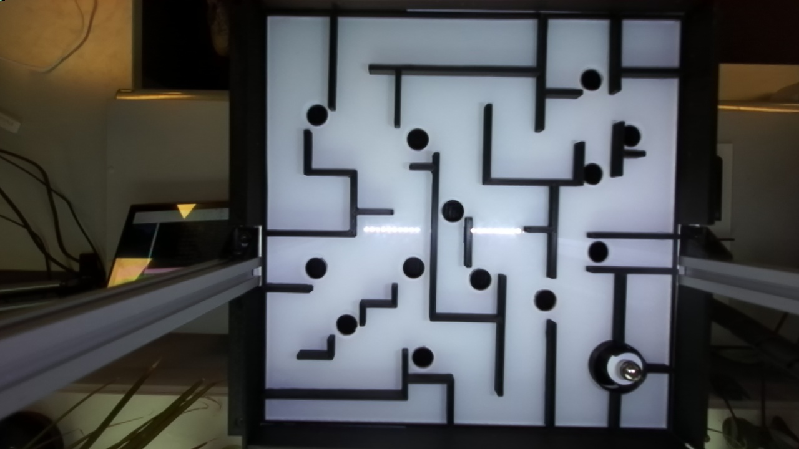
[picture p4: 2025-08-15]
jetson/src/MAZE_PICS/Hard.jpg

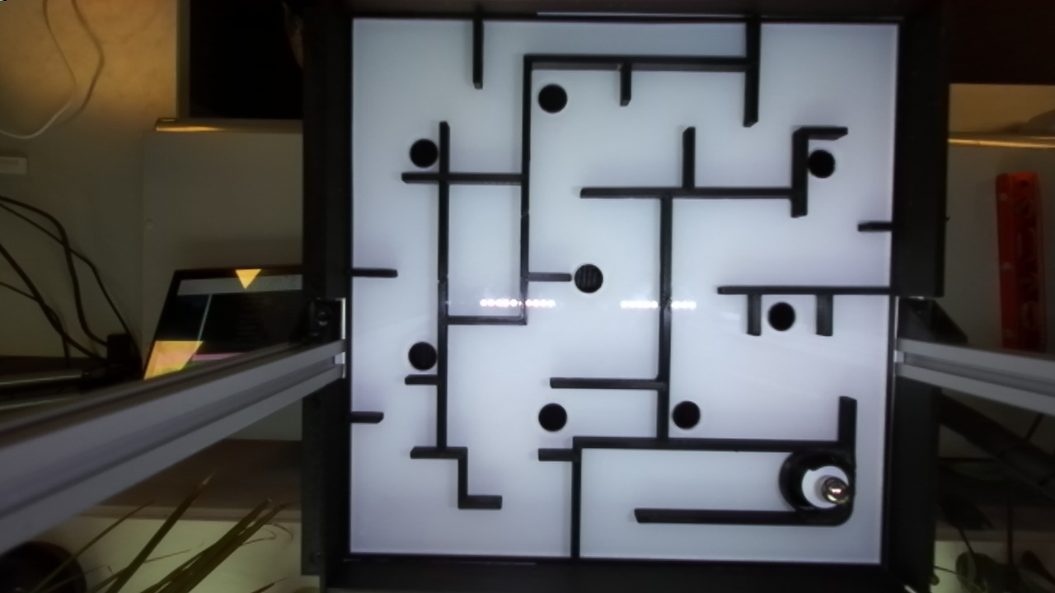
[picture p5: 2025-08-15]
jetson/src/MAZE_PICS/Easy.jpg

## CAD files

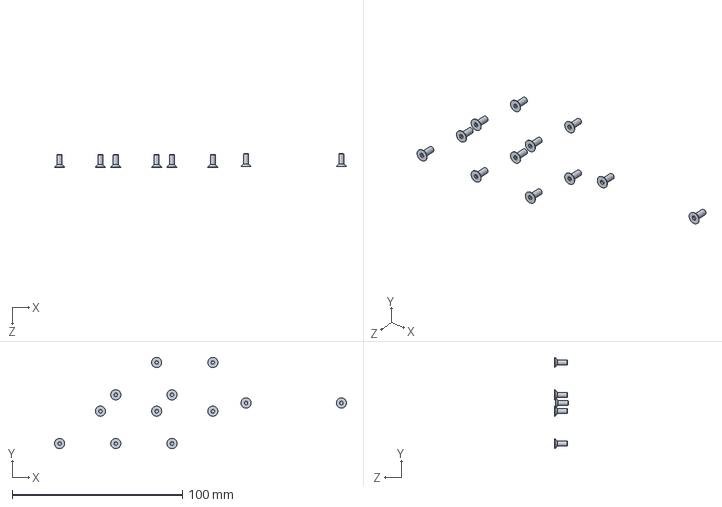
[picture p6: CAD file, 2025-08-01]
3d_modeler/sammensetning/vegger/vegg_bak_sammensetning.SLDASM
171.5 x 53.6 x 8.15 mm
skrue_m3x6 x 12

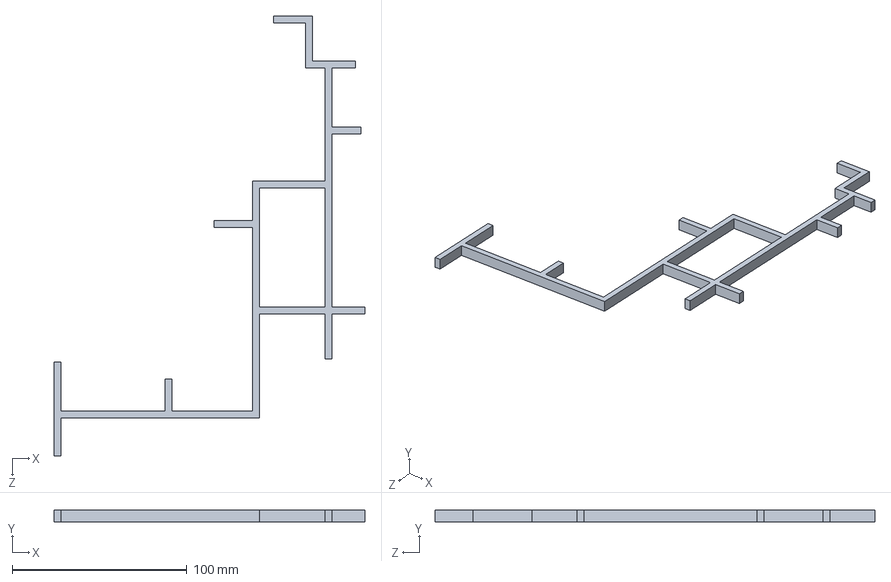
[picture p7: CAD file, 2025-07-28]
3d_modeler/labyrint/labyrint_lett/vegger_separat/vegg_4.SLDPRT
177.8 x 7.00 x 251.4 mm

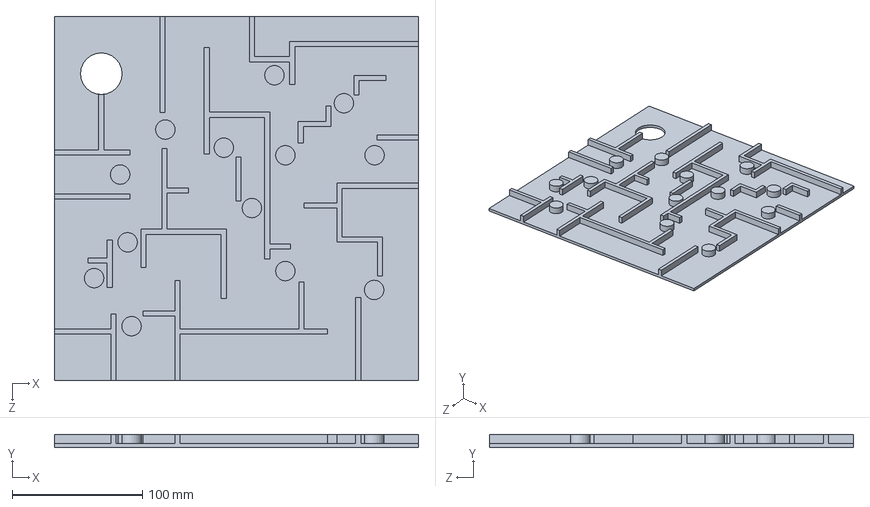
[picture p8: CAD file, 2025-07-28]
3d_modeler/labyrint/labyrint_mellom/labyrint_mellom.SLDPRT
280.0 x 10.0 x 280.0 mm

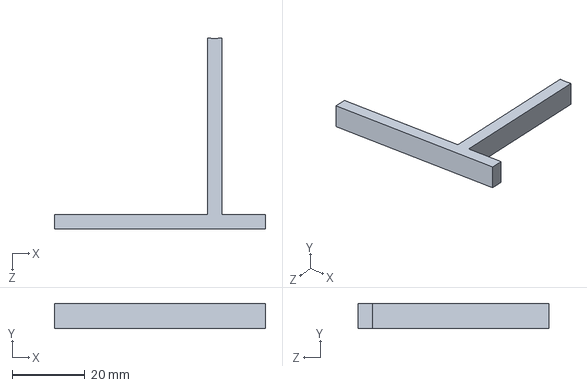
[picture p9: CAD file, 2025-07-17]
3d_modeler/labyrint/labyrint_mellom/vegger/vegg_2.SLDPRT
58.0 x 7.00 x 52.5 mm

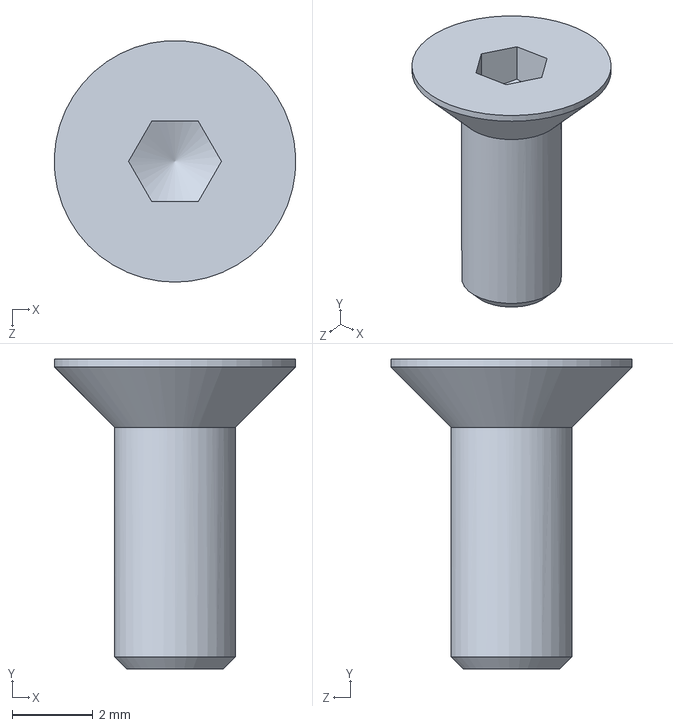
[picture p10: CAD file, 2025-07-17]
3d_modeler/sammensetning/aluminiumsprofiler/skrue_m3x6.SLDPRT
6.00 x 7.70 x 5.99 mm

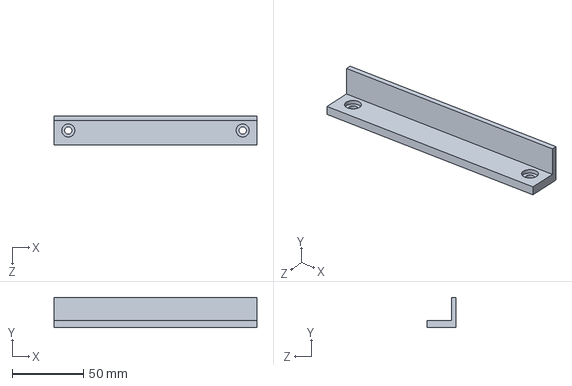
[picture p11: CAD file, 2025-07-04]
3d_modeler/sammensetning/bane_vegger/bane_vegg_142.SLDPRT
142.0 x 21.0 x 20.4 mm

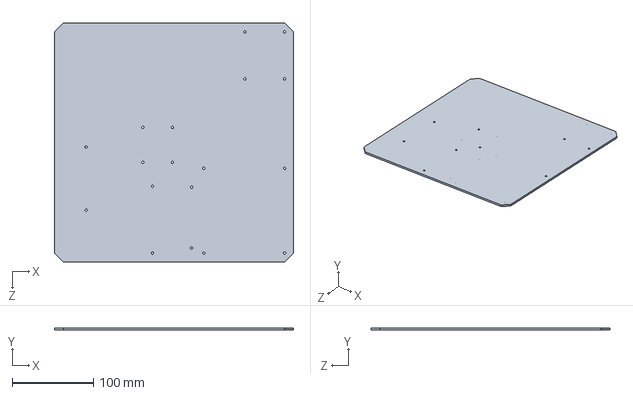
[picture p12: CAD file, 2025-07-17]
3d_modeler/sammensetning/komponenter/komponent_holder_plate.SLDPRT
295.0 x 3.00 x 295.0 mm

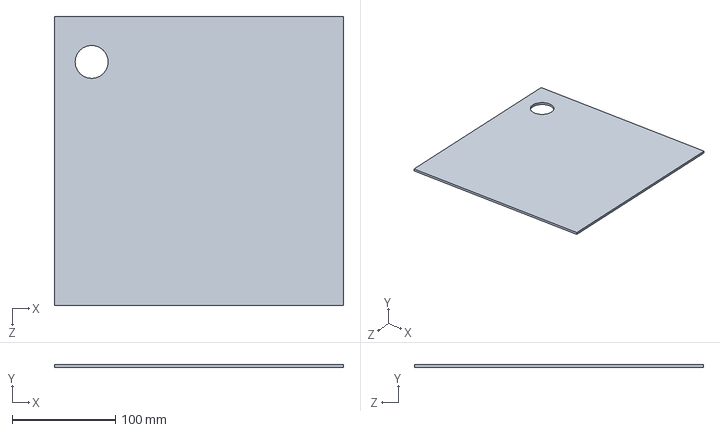
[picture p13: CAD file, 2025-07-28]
3d_modeler/sammensetning/labyrint_plate/labyrint_plate.SLDPRT
280.0 x 3.00 x 280.0 mm

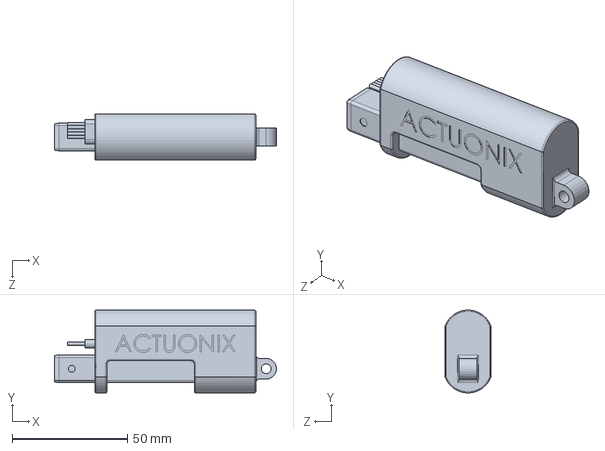
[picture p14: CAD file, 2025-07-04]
3d_modeler/sammensetning/motor/ACTUONIX-P16-50-64-12-P_HOUSING.SLDPRT
96.5 x 36.0 x 20.0 mm

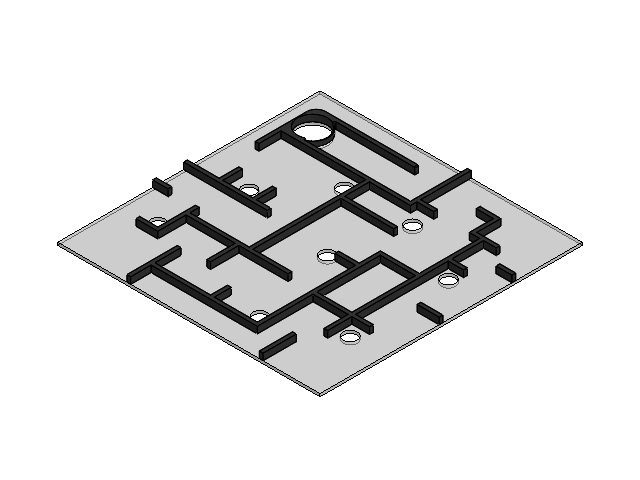
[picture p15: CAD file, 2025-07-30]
3d_modeler/labyrint/labyrint_lett/labyrint_lett.SLDASM
labyrint_lett_plate
labyrint_lett_vegger

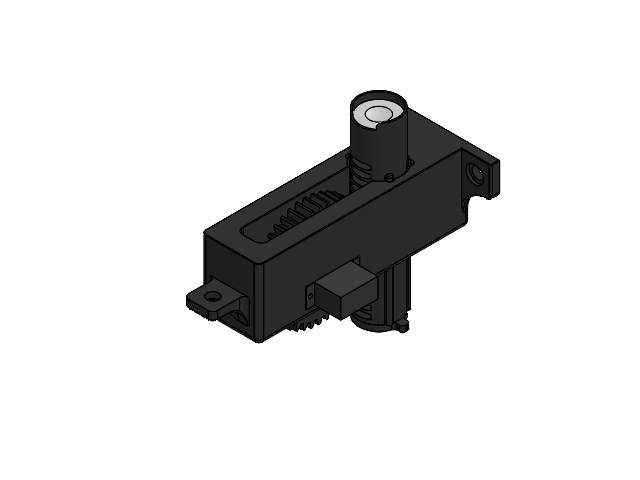
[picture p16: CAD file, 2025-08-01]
3d_modeler/sammensetning/ball_heis/heis.SLDASM
heis_holder
tannhjul
heis_stag
heis_stag_stopper
heis_stag_topp_inlegg
skrue_m3x6
servo_hus
servo_arm

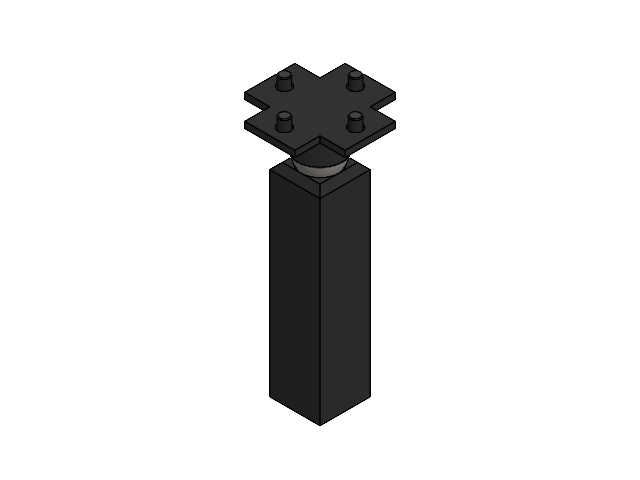
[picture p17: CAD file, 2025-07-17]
3d_modeler/sammensetning/kuleledd/kuleledd.SLDASM
kuleledd_nede
kule
kuleledd_oppe
skrue_m5x8 x 4

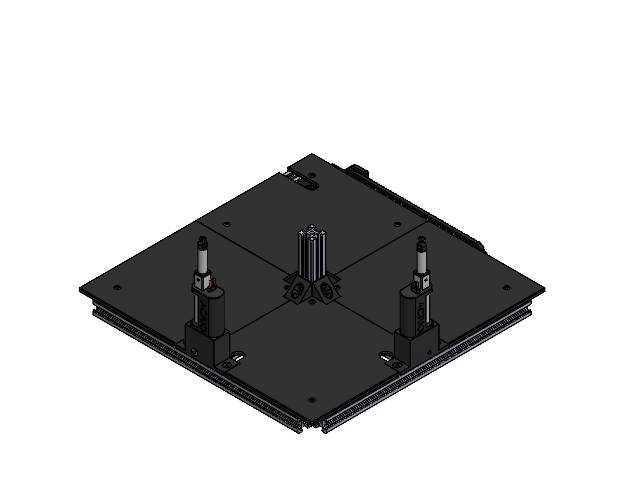
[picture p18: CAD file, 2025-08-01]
3d_modeler/sammensetning/midt_ramme.SLDASM
hjørne_kobling_midt x 16
20x20x285 x 5
20x20x132_5 x 2
20x20x70_5
hjørne_kobling x 4
motor_holder_nede x 2
ACTUONIX-P16-50-64-12-P_HOUSING x 2
ACTUONIX-P16-50-64-12-P_ROD x 2
topp_lokk_høyre_bak
topp_lokk_høyre_forann
topp_lokk_venstre_bak
topp_lokk_venstre_forann
transport_stag
transport_holder_nede
treplugg
transport_holder_nede_ende
skrue_m3x6 x 16
skrue_m5x8 x 49
socket countersunk head screw_iso x 2

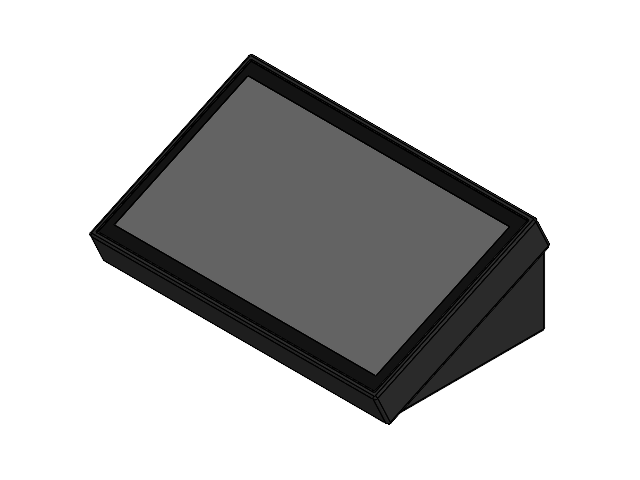
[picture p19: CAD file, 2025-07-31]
3d_modeler/skjerm_stativ/skjerm_stativ.SLDASM
skjerm_deksel
skjerm_bein_venstre
skjerm_bein_høyre
tapp x 2
10.1inch HDMI.stp
skrue_m3x6 x 4
spennings_avlaster

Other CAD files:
3d_modeler/sammensetning/ball_heis/heis_stag_med_stopper.SLDASM
3d_modeler/sammensetning/motor/ACTUONIX-P16-50-64-12-P_ASSEMBLY.SLDASM
3d_modeler/sammensetning/nedre_ramme.SLDASM
3d_modeler/sammensetning/ball_heis/servo.SLDASM
3d_modeler/labyrint/labyrint_lett/labyrint_lett_plate.SLDPRT
3d_modeler/labyrint/labyrint_lett/labyrint_lett_vegger.SLDPRT
3d_modeler/labyrint/labyrint_lett/vegger_separat/vegg_1.SLDPRT
3d_modeler/labyrint/labyrint_lett/vegger_separat/vegg_1_a.SLDPRT
3d_modeler/labyrint/labyrint_lett/vegger_separat/vegg_1_b.SLDPRT
3d_modeler/labyrint/labyrint_lett/vegger_separat/vegg_2.SLDPRT
3d_modeler/labyrint/labyrint_lett/vegger_separat/vegg_3.SLDPRT
3d_modeler/labyrint/labyrint_lett/vegger_separat/vegg_4_a.SLDPRT
3d_modeler/labyrint/labyrint_lett/vegger_separat/vegg_4_b.SLDPRT
3d_modeler/labyrint/labyrint_lett/vegger_separat/vegg_5.SLDPRT
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

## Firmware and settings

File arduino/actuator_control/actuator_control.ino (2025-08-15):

// Inkluderer nødvendige biblioteker
#include <Servo.h> // For servo kontroll
#include <Adafruit_NeoPixel.h> // For styring av NeoPixel LED

// Initialiserer variabler
// Navnerom for aktuatorene
namespace actuators {
    
    // Struct for pinnenummerene
    struct ActuatorData
    {
        const uint8_t pwm_up; // Pinne for PWM oppover
        const uint8_t pwm_down; // Pinne for PWM nedover
        const uint8_t pot_feedback; // Pinne for potensjometer
        float position; // Posisjon til aktuatoren (mm)
        int8_t distance_status; // Motor status. -1 er under nedre grense, 1 er over øvre grense
    };

    // Aktuator en
    ActuatorData actuator_1 = {9, 10, A4, 0, 0}; // PWM oppover = 9, PWM nedover = 10, Potensjometer = A4

    // Aktuator to
    ActuatorData actuator_2 = {11, 12, A3, 0, 0}; // PWM oppover = 11, PWM nedover = 12, Potensjometer = A3
}

namespace lift_servo {
    Servo lift; // Servo for heis
    const uint8_t servo_pin = 5; // Pinne for servo
    const uint8_t lift_down = 170; // Lav posisjon for heis
    const uint8_t lift_up = 20; // Høy posisjon for heis
    const uint8_t lift_stop = 90; // Stopp posisjon for heis
    unsigned long elevator_start_time = 0; // Tidspunkt for når heisen startet å kjøre
    bool elevator_running = false; // Variabel for å sjekke om heisen er aktiv
}

namespace led_strips {
    const uint8_t led_pin = 7; // Pinne for LED strip
    const uint16_t num_leds = 10; // Antall LED i stripen 
    Adafruit_NeoPixel strip = Adafruit_NeoPixel(num_leds, led_pin, NEO_GRB + NEO_KHZ800); // Initialiserer LED stripen
}

namespace serial_messages {
    // Enum for tilstander i programmet
    enum class State
    {
        IDLE, // Tilstand for å vente på kommandoer
        ELEVATOR, // Tilstand for å hente ball
        CONTROL, // Tilstand for å kontrollere aktuatorene
        SET_COLOR // Tilstand for å sette farge på LED stripen
    };

    State state = State::IDLE; // Initialiserer tilstanden til IDLE

    // Variabler for seriedata
    int16_t value_1 = 0; // Variabel for første verdi i seriedata
    int16_t value_2 = 0; // Variabel for andre verdi i seriedata
    int16_t value_3 = 0; // Variabel for tredje verdi i seriedata
    int16_t value_4 = 0; // Variabel for fjerde verdi i seriedata
}

// Navnerom for globale variabler
namespace {
    // Teller for hvor ofte grensen sjekkes for aktuatorene
    uint8_t limit_check_counter = 0;
}

// Initialiserer funksjoner
void stop_actuators(); // Funksjon for å stoppe aktuatorene
void actuator_position(); // Funksjon for posisjonen til aktuatoren
void actuator_limit_check(); // Funksjon for å sjekke om aktuatoren er over eller under ønsket maks eller min høyde
void move_speed(int16_t speed_actuator_1, int16_t speed_actuator_2); // Funksjon for å bevege begge aktuatorene med hastighetene i actuator_speeds
void elevator(int8_t elevator_dir); // Funksjon for å kontrollere heisen for å hente ball
void set_led_color(uint8_t r, uint8_t g, uint8_t b, int8_t led_number); // Funksjon for å sette fargen på LED stripen
void read_serial(); // Funksjon for å lese innkommende seriedata

void setup() {
    // Starter seriel kominikasjon
    Serial.begin(115200);

    // Initialiserer LED stripen
    led_strips::strip.begin(); // Starter LED stripen
    led_strips::strip.setBrightness(255); // Setter lysstyrken til stripen
    // Setter alle LED til hvit farge
    set_led_color(255, 255, 255, -1); // Setter fargen til hvit

    // Setter pin modusene
    // Aktuator en
    pinMode(actuators::actuator_1.pwm_up, OUTPUT); // Setter PWM pinne for aktuator en oppover
    pinMode(actuators::actuator_1.pwm_down, OUTPUT); // Setter PWM pinne for aktuator en nedover

    // Aktuator to
    pinMode(actuators::actuator_2.pwm_up, OUTPUT); // Setter PWM pinne for aktuator to oppover
    pinMode(actuators::actuator_2.pwm_down, OUTPUT); // Setter PWM pinne for aktuator to nedover

    // Setter analog pinnene til null for at motorene ikke bevege seg når programmet starter
    stop_actuators(); // Stopper aktuatorene
/*
    lift_servo::lift.attach(lift_servo::servo_pin);
    lift_servo::lift.write(0);
    delay(500);
    lift_servo::lift.detach();
    */
}

void loop() {
    read_serial(); // Motar data over seriel fra Jetson

    switch (serial_messages::state) // Sjekker hvilken tilstand programmet er i
    {
        case serial_messages::State::ELEVATOR: // Tilstand 0: Heis klar til å hente ball

            // Sjekk om heisen heisen står stille og om det er over 1s siden den ble kjørt sist
            if (lift_servo::elevator_running == false)
            {
                elevator(serial_messages::value_1); // Kjører heisen
            }
            else
            {
                // Gjør ingen ting
            }
            
            serial_messages::state = serial_messages::State::IDLE; // Går til neste tilstand
            break;
        case serial_messages::State::CONTROL: // Tilstand 1: Kontrollerer aktuatorene
            actuator_limit_check(); // Sjekker om aktuatorene er over eller under grensen og oppdaterer distance_status
            move_speed(serial_messages::value_1, serial_messages::value_2); // Setter motor hastighetene
            break;
        case serial_messages::State::SET_COLOR: // Tilstand 2: Setter farge på LED stripen
            set_led_color(serial_messages::value_1, serial_messages::value_2, serial_messages::value_3, serial_messages::value_4); // Setter fargen på LED stripen
            serial_messages::state = serial_messages::State::IDLE; // Går til neste tilstand
            break;
        default: // Standard tilstand: Ingen handling
            stop_actuators(); // Stopper aktuatorene
            break;
    }

    if (lift_servo::elevator_running == true && millis() - lift_servo::elevator_start_time >= 200)
    {
        elevator(0);
        lift_servo::elevator_running = false;
        
    }
}

void stop_actuators()
{
    // Funksjon for å stoppe aktuatorene
    // Aktuator en
    analogWrite(actuators::actuator_1.pwm_up, 0); // Setter PWM pinne for aktuator en oppover til 0
    analogWrite(actuators::actuator_1.pwm_down, 0); // Setter PWM pinne for aktuator en nedover til 0
    actuators::actuator_1.position = 0; // Nullstiller posisjonen til aktuator en

    // Aktuator to
    analogWrite(actuators::actuator_2.pwm_up, 0); // Setter PWM pinne for aktuator to oppover til 0
    analogWrite(actuators::actuator_2.pwm_down, 0); // Setter PWM pinne for aktuator to nedover til 0
    actuators::actuator_2.position = 0; // Nullstiller posisjonen til aktuator to
}

// Funksjon for å returnere posisjonen til aktuatoren
void actuator_position() // Tar inn en peker til potensjometer pinnen
{
    const float act_max_stroke{50.0}; // Maks slaglengde for aktuatorene (mm)
    const float adc_max_hight{1018.0}; // ADC verdien for maks lengde
    const float adc_min_hight{2.0}; // ADC verdi for minimum lengde

    // Kalkulerer distansen til aktuator en
    actuators::actuator_1.position = (float(analogRead(actuators::actuator_1.pot_feedback)) - adc_min_hight) * act_max_stroke / (adc_max_hight - adc_min_hight);
    // Kalkulerer distansen til aktuator to
    actuators::actuator_2.position = (float(analogRead(actuators::actuator_2.pot_feedback)) - adc_min_hight) * act_max_stroke / (adc_max_hight - adc_min_hight);
}

// Funksjon for å sjekke om aktuatorene er over eller under grensen
void actuator_limit_check()
{   
    const uint8_t limit_check_interval = 10; // Sjekk grenser kun hver 10. loop

    limit_check_counter++; // Øker telleren for hvor ofte grensen sjekkes
    if (limit_check_counter < limit_check_interval) // Sjekker ikke grensen for ofte
    {
        return; // Ikke sjekk grensen
    }
    else
    {
        limit_check_counter = 0; // Nullstiller telleren
    }

    const float act_max_stroke{50.0}; // Maks slaglengde for aktuatorene (mm)
    const float offset{3.0}; // Distansen fra toppen og bunden hvor aktuatorene ikke skal gå innenfor (mm)

    actuator_position(); // Leser inn posisjonen til aktuatorene

    // Sjekker aktuator en
    if (actuators::actuator_1.position >= act_max_stroke - offset) // Hvis aktuator en
    {
        actuators::actuator_1.distance_status = 1; // Setter status til 1 (for høyt)
    }
    else if (actuators::actuator_1.position <= offset) // Hvis aktuator en er for lavt
    {
        actuators::actuator_1.distance_status = -1; // Setter status til -1 (for lavt)
    }
    else // Hvis aktuator en er innenfor grensen
    {
        actuators::actuator_1.distance_status = 0; // Setter status til 0 (OK)
    }

    // Sjekker aktuator to
    if (actuators::actuator_2.position >= act_max_stroke - offset) // Hvis aktuator to er for høyt
    {
        actuators::actuator_2.distance_status = 1; // Setter status til 1 (for høyt)
    }
    else if (actuators::actuator_2.position <= offset) // Hvis aktuator to er for lavt
    {
        actuators::actuator_2.distance_status = -1; // Setter status til -1 (for lavt)
    }
    else // Hvis aktuator to er innenfor grensen
    {
        actuators::actuator_2.distance_status = 0; // Setter status til 0 (OK)
    }
}

// Funksjon for å sette hastighetene til aktuatorene basert på actuator_speeds
void move_speed(int16_t speed_actuator_1, int16_t speed_actuator_2)
{
    // Aktuator 1
    if (speed_actuator_1 > 0 && actuators::actuator_1.distance_status != 1) // Hvis aktuator en skal bevege seg oppover og ikke er for høyt
    {
        analogWrite(actuators::actuator_1.pwm_up, speed_actuator_1);
        analogWrite(actuators::actuator_1.pwm_down, 0);
    } 
    else if (speed_actuator_1 < 0 && actuators::actuator_1.distance_status != -1) // Hvis aktuator en skal bevege seg nedover og ikke er for lavt
    {
        analogWrite(actuators::actuator_1.pwm_up, 0);
        analogWrite(actuators::actuator_1.pwm_down, -speed_actuator_1); // - for å få riktig retning
    }
    else // Hvis aktuator en ikke skal bevege seg
    {
        analogWrite(actuators::actuator_1.pwm_up, 0);
        analogWrite(actuators::actuator_1.pwm_down, 0);
    }
    
    // Aktuator 2
    if (speed_actuator_2 > 0 && actuators::actuator_2.distance_status != 1) // Hvis aktuator to skal bevege seg oppover og ikke er for høyt
    {
        analogWrite(actuators::actuator_2.pwm_up, speed_actuator_2);
        analogWrite(actuators::actuator_2.pwm_down, 0);
    } 
    else if (speed_actuator_2 < 0 && actuators::actuator_2.distance_status != -1) // Hvis aktuator to skal bevege seg nedover og ikke er for lavt
    {
        analogWrite(actuators::actuator_2.pwm_up, 0);
        analogWrite(actuators::actuator_2.pwm_down, -speed_actuator_2); // - for å få riktig retning
    }
    else // Hvis aktuator to ikke skal bevege seg
    {
        analogWrite(actuators::actuator_2.pwm_up, 0);
        analogWrite(actuators::actuator_2.pwm_down, 0);
    }
}

void elevator(int8_t elevator_dir)
{
    if (lift_servo::lift.attached() == false && lift_servo::elevator_running == false)
    {
        lift_servo::lift.attach(lift_servo::servo_pin);
    }
    else if (lift_servo::lift.attached() == true && lift_servo::elevator_running == true)
    {
        lift_servo::lift.detach();
        return;
    }
    else
    {
        // Gjør ingenting
    }

    if (elevator_dir == -1 && lift_servo::lift.read() != lift_servo::lift_down)
    {
        lift_servo::lift.write(lift_servo::lift_down);
        lift_servo::elevator_start_time = millis();
        lift_servo::elevator_running = true;
    }
    else if (elevator_dir == 1 && lift_servo::lift.read() != lift_servo::lift_up)
    {
        lift_servo::lift.write(lift_servo::lift_up);
        lift_servo::elevator_start_time = millis();
        lift_servo::elevator_running = true;
    }
    else
    {
      lift_servo::lift.detach();
        // Gjør ingenting
    }
}


// Funksjon for å sette fargen på LED stripen
void set_led_color(uint8_t r, uint8_t g, uint8_t b, int8_t led_number) {

    // Setter alle LED til en spesifikk farge
    if (led_number == -1)
    {
        for (uint8_t i = 0; i < led_strips::num_leds; i++) {
        led_strips::strip.setPixelColor(i, led_strips::strip.Color(r, g, b)); // Setter fargen på hver LED
        }
    }
    // Setter en spesifikk LED til en spesifikk farge
    else if (led_number >= 0 && led_number < led_strips::num_leds)
    {
        led_strips::strip.setPixelColor(led_number, led_strips::strip.Color(r, g, b)); // Setter fargen på den spesifikke LED
    }
    else
    {
        Serial.println("Invalid LED number!"); // Skriver ut en feilmelding hvis led_number er utenfor gyldig område
        return; // Avslutter funksjonen tidlig
    }
    led_strips::strip.show(); // Oppdaterer stripen for å vise endringene
}

// Funksjon for å lese innkommende seriedata
void read_serial()
{
    // Leser innkommende seriedata fra Jetson
    if (Serial.available() <= 0)
    {
        return; // Hvis det ikke er noen data tilgjengelig, bare avslutt funksjonen.
    }

    // Nullstiller verdiene
    serial_messages::value_1 = 0; 
    serial_messages::value_2 = 0;
    serial_messages::value_3 = 0;
    serial_messages::value_4 = 0;

    char buffer[64]; // Buffer for å lagre innkommende data
    int len = Serial.readBytesUntil('\n', buffer, sizeof(buffer) - 1); // Leser data til linjeskift eller buffer er fullt

    // Legg til sjekk for å sikre at vi faktisk leste noe før vi parser
    if (len > 0)
    {
        buffer[len] = '\0'; // Null-terminerer strengen for sikkerhet
            
        int v1, v2, v3, v4, incoming_state;

        // Tell antall kommaer for å bestemme meldingstype raskt
        uint8_t comma_count = 0;
        for (int i = 0; i < len; i++)
        {
            if (buffer[i] == ',')
            {
                comma_count++;
            }
        }
        
        // Sjekk for den vanligste meldingen FØRST: CONTROL (2 hastigheter + state)
        if (comma_count == 2) // For CONTROL-meldinger (f.eks. "25,200,1")
        {
            if (sscanf(buffer, "%d,%d,%d", &v1, &v2, &incoming_state) != 3)
            {
                return; // Ugyldig format, ignorer meldingen
            }

            if (incoming_state < 0 || incoming_state > 3)
            {
                return; // Ugyldig state, ignorer meldingen
            }

            serial_messages::value_1 = v1;
            serial_messages::value_2 = v2;
            serial_messages::state = static_cast<serial_messages::State>(incoming_state);

            return; // Avslutter funksjonen siden meldingen er lest
        }

        // Sjekker for get_ball-meldinger: GET_BALL
        else if (comma_count == 1) // For GET_BALL-meldinger (f.eks. "1, 0" eller "-1, 1")
        {
            if (sscanf(buffer, "%d,%d", &v1, &incoming_state) != 2)
            {
                return; // Ugyldig format, ignorer meldingen
            } 
                
            if (incoming_state < 0 || incoming_state > 3)
            {
                return; // Ugyldig state, ignorer meldingen
            }

            serial_messages::value_1 = v1;
            serial_messages::state = static_cast<serial_messages::State>(incoming_state);

            return; // Avslutter funksjonen siden meldingen er lest
        }

        // Sjekk deretter for den lengste: SET_COLOR (3 fargeverdier + state)
        else if (comma_count == 4) // For SET_COLOR-meldinger (f.eks. "255,0,0,3")
        {
            if (sscanf(buffer, "%d,%d,%d,%d,%d", &v1, &v2, &v3, &v4, &incoming_state) != 5)
            {
                return; // Ugyldig format, ignorer meldingen
            }

            if (incoming_state < 0 || incoming_state > 3)
            {
                return; // Ugyldig state, ignorer meldingen
            }

            serial_messages::value_1 = v1;
            serial_messages::value_2 = v2;
            serial_messages::value_3 = v3;
            serial_messages::value_4 = v4;
            serial_messages::state = static_cast<serial_messages::State>(incoming_state);

            return; // Avslutter funksjonen siden meldingen er lest
        }

        // Sjekk til slutt for den korteste: IDLE/GET_BALL (kun state)
        else if (comma_count == 0) // For IDLE/GET_BALL-meldinger (f.eks. "0")
        {
            if (sscanf(buffer, "%d", &incoming_state) != 1)
            {
                return; // Hvis sscanf ikke klarer å lese fem verdier, hopp over denne meldingen
            }

            if (incoming_state < 0 || incoming_state > 3)
            {
                return; // Hvis state ikke er gyldig, hopp over denne meldingen
            }

            serial_messages::state = static_cast<serial_messages::State>(incoming_state);
        }
    }
}

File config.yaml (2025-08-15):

animations:
  locating_ball:
    fps: 30
  path_finding:
    fps: 8
camera:
  bottom_left:
  - 430
  - 682
  bottom_right:
  - 1085
  - 682
  coordinate_units: MILLIMETER
  depth_mode: NONE
  elevator_center_x: 998
  elevator_center_y: 588
  elevator_radius: 60
  fps: 60
  maze_height: 655
  maze_image_scale: 0.87
  maze_offset_x: 430
  maze_offset_y: 27
  maze_relative_angle: 1
  maze_width: 655
  padding: 20
  resolution: HD720
  top_left:
  - 430
  - 27
  top_right:
  - 1085
  - 27
controller:
  angular_controller:
    angle_tolerance: 0.001
    command_delay: 0.0001
    kp: 6500
    max_angle: 1.4
  arduino:
    maximum_velocity: 100
    minimum_velocity: 22
    minimum_velocity_difference: 5
    motor_smoothing_alpha: 0.15
    x_offset: 0.014
    x_offset_temp: 0.014
    y_offset: 0.0
    y_offset_temp: 0.5
  horizontal_controller:
    kp: 900
    time_limit: 10
    tolerance: 0.002
  integration_pos_threshold: 80
  integration_vel_threshold: 40
  position_controller_lookahead:
    feedforward_t: 10.5
    kd_x: 0.0045
    kd_y: 0.0045
    ki_x: 0.0002
    ki_y: 0.0002
    kp_x: 1.0e-05
    kp_y: 1.0e-05
    position_tolerance: 35
    velocity_tolerance: 20
  position_controller_normal:
    feedforward_t: 7.8
    kd_x: 8.5e-05
    kd_y: 8.5e-05
    ki_x: 0.0004
    ki_y: 0.0004
    kp_x: 4.0e-05
    kp_y: 4.0e-05
    position_tolerance: 25
    velocity_tolerance: 20
  position_smoothing_alpha: 0.1
  stuck_time_threshold: 0.5
  stuck_unstuck_hold_time: 0.2
  stuck_upper_position_threshold: 70
  stuck_velocity_threshold: 30
  stuck_wiggle_amplitude: 0.4
  stuck_wiggle_frequency: 20
  velocity_smoothing_alpha: 0.99
  wiggle_direction_bias: 0.007
game:
  ball_lost_timeout: 1
  goal_position:
    x: 763
    y: 49
  goal_radius: 30
  maze_id: 1
  player_name: Player
general:
  get_ball_delay: 4
  idle_light_time: 15
path_finding:
  adaptive_threshold_target: 130
  astar_downscale: 1.0
  clahe_clip_limit: 1.0
  clear_path_kernel_size: 6
  dilation_iterations: 2
  min_safe_distance: 14
  path_cache_file: control/astar/path_cache.json
  path_cache_size: 30
  path_cache_tolerance: 15
  repulsion_weight: 10
path_following:
  lookahead:
    adaptive: false
    curvature_gain: 0.99
    lookahead_distance: 75
    lookahead_distance_max: 100
    lookahead_distance_min: 60
    smoothing_alpha: 0.03
    velocity_gain: 150
  normal:
    checkpoint_timeout: 10
    dwell_time: 0.35
    stuck_retry_time: 3
    velocity_threshold: 50
tracking:
  box_iou_threshold: 0.4
  hsv_window_size: 80
  init_ball_region:
    x_max: 1200
    x_min: 420
    y_max: 700
    y_min: 25
  model_path: tracking/v8-512.engine
  smoothing_alpha: 0.5
  yolo_cooldown_period: 20
  yolo_frame_interval: 5

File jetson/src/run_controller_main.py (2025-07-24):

import time
from mqtt_client import MQTTClientJetson
import position_controller
import utils.low_pass_filter
import path_following
import path_following_lookahead
import utility_threads
from image_controller import ImageController
from image_controller import ImageSenderThread
from camera.tracker_service import TrackerService
from logger import LoggingThread

def main(tracker: TrackerService,
         controller: position_controller.Controller,
         mqtt_client: MQTTClientJetson,
         path_array=None,
         image_controller:ImageController = None,
         stop_event=None,
         config=None):

    smoother = utils.low_pass_filter.SmoothedTracker(alpha=0.5)

    ball_not_found_timer = None
    ball_not_found_limit = 60  # seconds

    print("[INFO] Waiting for YOLO initialization...")
    while not tracker.is_initialized:
        time.sleep(0.1)
    print("[INFO] Tracking initialized.")

    if controller.lookahead:
        print("[INFO] Using lookahead path following.")
        pathFollower = path_following_lookahead.PathFollower(path_array, controller, config)
    else:
        print("[INFO] Using standard path following.")
        pathFollower = path_following.PathFollower(path_array, controller, config)

    image_thread = ImageSenderThread(image_controller, mqtt_client, tracker, path_array, pathFollower, stop_event=stop_event)
    image_controller.set_new_path(path_array)
    image_thread.start()

    controller.horizontal()
    escape_thread = utility_threads.EscapeElevatorThread(controller.arduinoThread, controller)
    escape_thread.start()
    time.sleep(escape_thread.duration)
    controller.horizontal()

    logger = None
    logger = LoggingThread(path_array)
    logger.start()
    controller.logger = logger

    TARGET_HZ = 60
    LOOP_DT = 1.0 / TARGET_HZ
    blinker = None

    try:
        while not stop_event.is_set():
            loop_start = time.time()

            frame = tracker.get_stable_frame()
            if frame is None:
                time.sleep(0.015)
                continue

            image_controller.frame = frame.copy()
            ball_pos = tracker.get_ball_position()
            #print("orientation:", tracker.get_orientation())
            if ball_pos is not None:
                ball_pos = smoother.update(ball_pos)
                pathFollower.follow_path(ball_pos)
                logger.set_waypoint(pathFollower.get_current_waypoint())

                if blinker is not None:
                    blinker.stop()
                    if blinker.triggered:
                        escape_thread = utility_threads.EscapeElevatorThread(controller.arduinoThread, controller)
                        escape_thread.start()
                        time.sleep(escape_thread.duration)
                        controller.horizontal()
                        if controller.lookahead:
                            print("[INFO] Using lookahead path following.")
                            pathFollower = path_following_lookahead.PathFollower(path_array, controller, config)
                            image_thread.path_follower = pathFollower
                        else:
                            print("[INFO] Using standard path following.")
                            pathFollower = path_following.PathFollower(path_array, controller, config)
                            image_thread.path_follower = pathFollower
                    blinker = None
                    ball_not_found_timer = None
            else:
                ball_pos = smoother.update(ball_pos)

                if blinker is None:
                    controller.arduinoThread.send_speed(0, 0)
                    blinker = utility_threads.BlinkRed(controller.arduinoThread, config, controller)
                    blinker.start()
                    ball_not_found_timer = time.time()

            if ball_not_found_timer is not None:
                elapsed_time = time.time() - ball_not_found_timer
                if elapsed_time > ball_not_found_limit:
                    print("[WARNING] Ball not found for too long, returning to main menu.")
                    controller.arduinoThread.send_speed(0, 0)
                    ball_not_found_timer = None
                    mqtt_client.client.publish("pi/info", "timeout")
                    break
            
            loop_duration = time.time() - loop_start
            sleep_time = LOOP_DT - loop_duration
            if sleep_time > 0:
                time.sleep(sleep_time)

    except KeyboardInterrupt:
        print("\n[INFO] Interrupted by user.")
    except Exception as e:
        import traceback
        print(f"[ERROR] Control loop crashed: {e}")
        traceback.print_exc()
    finally:
        print("[INFO] Control thread exited.")
        if blinker is not None:
            blinker.stop()
            blinker = None
        controller.arduinoThread.send_speed(0, 0)
        if image_thread.is_alive():
            image_thread.stop()
            image_thread.join()
        if logger is not None:
            logger.stop()
            logger = None

if __name__ == "__main__":
    main()

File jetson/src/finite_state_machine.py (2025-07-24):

import cmd
from enum import Enum, auto
import time
from mqtt_client import MQTTClientJetson
from arduino_connection import ArduinoConnection
from camera.tracker_service import TrackerService
import utility_threads
from image_controller import ImageController
from image_controller import ImageSenderThread
from utils.joystick_controller import JoystickController
import position_controller
from utility_functions import is_in_elevator, remove_withing_elevator
import run_controller_main
import threading
import os
import sys
from typing import Dict, Any
from utils.leaderboard_utils import add_score
from datetime import datetime


class SystemState(Enum):
    BOOTING = auto()
    MAIN_SCREEN = auto()
    INFO_SCREEN = auto()
    NAVIGATION = auto()
    LOCATING = auto()
    AUTO_PATH = auto()
    CUSTOM_PATH = auto()
    CONTROLLING = auto()
    HUMAN_CONTROLLER = auto()
    PRACTICE = auto()
    PLAYALONE = auto()
    PLAYALONE_START = auto()
    LEADERBOARD = auto()

class HMIController:
    def __init__(self, tracking_service: TrackerService, arduino_thread: ArduinoConnection, mqtt_client: MQTTClientJetson, config: Dict[str, Any]):
        self.state = SystemState.BOOTING
        self.tracking_service = tracking_service
        self.arduino_thread = arduino_thread
        self.mqtt_client = mqtt_client
        self.loop_control = False
        self.ball_finder = None
        self.path = None
        self.path_lookahead = None
        self.image_controller = ImageController(config)
        self.image_thread = None
        self.controller = position_controller.Controller(arduino_thread, tracking_service, config=config)
        self.controller_thread = None
        self.stop_controller_event = threading.Event()
        self.custom_goal = None
        self.path_thread = None
        self.disco_mode = 0
        self.disco_thread = None
        self.loop_path = False
        self.config = config

    def restart_program(self):
        print("Restart requested...")
        self.stop_threads()
        python = sys.executable
        script = os.path.abspath(sys.argv[0])
        print(f"Launching new process: {python} {script}")
        #subprocess.Popen([python, script], start_new_session=True)
        #sys.exit(0)
        os.execv(python, [python, script])

    def stop_threads(self):
        try:
            self.mqtt_client.stop()
        except Exception as e:
            print(f"Error stopping MQTT client: {e}")
        if self.image_thread is not None:
            self.image_thread.stop()
            self.image_thread.join()
            self.image_thread = None
        if self.controller_thread is not None and self.controller_thread.is_alive():
            self.stop_controller_event.set()
            self.controller_thread.join()
            self.controller_thread = None
        if self.path_thread is not None and self.path_thread.is_alive():
            self.path_thread.stop()
            self.path_thread = None
        if self.ball_finder is not None:
            self.ball_finder.stop()
            self.ball_finder = None
        if self.disco_thread is not None:
            self.disco_thread.stop()
            self.disco_thread.join()
            self.disco_thread = None
        self.tracking_service.stop_tracker()
        self.tracking_service.camera.close()

    def stop_program(self):
        print("Stopping program...")
        self.stop_threads()
        sys.exit(0)

    def on_ball_found(self):
        if is_in_elevator(self.config, self.tracking_service.get_ball_position()):
            self.mqtt_client.client.publish("pi/info", "ball_found")
        else:
            self.ball_finder = utility_threads.LookForBall(
                    self.tracking_service, on_ball_found=self.on_ball_found
                )
            self.ball_finder.start_ball_check()

    def on_path_found(self, path, path_lookahead):
        self.path = path
        self.path_lookahead = path_lookahead
        if self.path is not None:
            self.mqtt_client.client.publish("pi/info", "path_found")
        else:
            self.mqtt_client.client.publish("pi/info", "path_not_found")
            if self.image_thread is None:
                self.image_thread = ImageSenderThread(self.image_controller, self.mqtt_client, self.tracking_service, self.path)
                self.image_thread.start()
            return
        self.path = remove_withing_elevator(self.config, self.path, radius=self.config['camera'].get('elevator_radius', 60))
        self.path_lookahead = remove_withing_elevator(self.config, self.path_lookahead, radius=self.config['camera'].get('elevator_radius', 60)+20)
        self.image_controller.set_new_path(self.path)
        if self.image_thread is None:
            self.image_thread = ImageSenderThread(self.image_controller, self.mqtt_client, self.tracking_service, self.path)
            self.image_thread.start()
    
    def stop_controller(self):
        if self.controller_thread is not None and self.controller_thread.is_alive():
            self.stop_controller_event.set()
            self.controller_thread.join()
            self.controller_thread = None
        self.arduino_thread.send_speed(0, 0)
        threading.Thread(target=self.controller.horizontal, daemon=True).start()

    def _start_joystick_control(self): # could be moved to sep file
        if hasattr(self, 'joystick_controller'):
            self.joystick_controller.stop()
            if hasattr(self, 'joystick_thread') and self.joystick_thread.is_alive():
                self.joystick_thread.join()

        self.joystick_controller = JoystickController(self.arduino_thread)
        self.joystick_thread = threading.Thread(target=self.joystick_controller.start, daemon=True)
        self.joystick_thread.start()

    def _ball_crossed_goal(self, position):
        goal_area = self.config.get("goal_area", {"x_min": 100, "x_max": 300, "y_min": 50, "y_max": 100})
        x, y = position
        return (goal_area["x_min"] <= x <= goal_area["x_max"] and
                goal_area["y_min"] <= y <= goal_area["y_max"])

    def run_playalone_game(self):
        print("[PLAYALONE] Starting tracking thread...")

        maze_id = self.config.get("maze_id", 1)
        player_name = self.config.get("player_name", "Unknown")

        self.tracking_service.start_tracker()

        game_running = True
        start_time = None
        last_valid_pos_time = time.time()

        while game_running:
            ball_pos = self.tracking_service.get_ball_position()

            if ball_pos is None:
                if start_time and (time.time() - last_valid_pos_time > 3):
                    print("[PLAYALONE] Game failed: ball lost > 3 seconds.")
                    self.mqtt_client.client.publish("pi/command", "playalone_fail")
                    break
            else:
                last_valid_pos_time = time.time()
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

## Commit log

2025-07-08 Fix circle drawing coordinates in safe_mask processing
    [fsm2.py]
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2025-07-08 Update path_found method to include mask parameter and adjust path finding thread to pass mask
2025-07-08 Fix image_controller frame assignment to use cropped_frame for sending safe mask
    [fsm2.py]
2025-07-08 Fix image_controller frame assignment to use safe_mask and ensure frame is processed before sending
    [fsm2.py]
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2025-07-08 Stop image thread before starting control loop in HMIController; rename retry button to start in AutoPathScreen
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2025-07-08 Fix image_thread handling in HMIController to prevent potential errors on state transition
    [fsm2.py]
2025-07-08 Enhance HMIController to manage controller thread lifecycle and add stop event handling
2025-07-08 Fix method signature for densify_path in HMIController
    [fsm2.py]
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2025-07-08 Remove debug print statement from on_path_found method and adjust speed parameters in EscapeElevatorThread run method
2025-07-08 Enhance create_binary_mask to filter green HSV values and improve mask quality; remove waypoint skipping in draw_path for direct path visualization
2025-07-08 Fix MQTT client publish method for timeout notification
    [run_controller_main.py]
2025-07-08 Reset image and waiting phase on frame show; add timeout check
2025-07-08 Add image update functionality in CustomPathScreen and start image thread on CUSTOM_PATH transition
2025-07-09 Refactor path finding logic in MQTTClientPi and CustomPathScreen; replace path_found flag with finding_path for clarity and improved state management
    [mqtt_client_2.py]
2025-07-09 Adjust status label position and ensure buttons are disabled during path calculation
2025-07-09 Swap custom_goal coordinates for correct goal assignment in start_path_finding
    [fsm2.py]
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2025-07-09 Enhance show_frame method to trigger UI refresh and configure event for improved frame display
2025-07-09 Enhance show_frame method to ensure window visibility before raising frame and triggering configure event
2025-07-09 Refactor MainApp initialization to streamline frame setup and ensure BootScreen is displayed correctly
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2025-07-09 Reset path and update image controller on navigation state transition
    [fsm2.py]
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2025-07-09 Refactor button handling in path finding screens to improve state management and UI responsiveness
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2025-07-09 Implement start command handling in HMIController to initiate pathfinding and manage controller thread
2025-07-09 Fix waypoint drawing logic in ImageController to use current_path instead of pathFollower
    [image_controller.py]
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2025-07-09 Refactor waypoint drawing logic in ImageController to use pathFollower and comment out image thread initialization in HMIController
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2025-07-09 Refactor HMIController to pass image_controller as an argument to the controller thread
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2025-07-09 Set current_path to None when no valid path is provided in set_new_path method
2025-07-09 Start image thread if not already running when setting a new path
2025-07-09 Remove debugging print statement in on_message and adjust image update calls in CustomPathScreen
2025-07-09 Refactor HMIController to streamline path finding and command handling; added timeout command support and ensured proper thread management.
2025-07-09 Refactor HMIController to run horizontal command in a separate thread; add DiscoThread for color control via Arduino.
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2025-07-09 Implement red chase effect in DiscoThread mode 6 with LED bouncing animation
2025-07-09 Simplify LED color setting in DiscoThread by sending color command for all LEDs at once
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2025-07-10 Enhance pathfinding and image handling by adding lookahead option and improving thread initialization
2025-07-10 Fix draw_waypoints_lookahead method to check for lookahead_point before drawing
    [image_controller.py]
2025-07-10 Update path follower to use controller's looping state and improve loop button styling in UI
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2025-07-10 Refactor waypoint advancement logic in PathFollower to support backward movement and remove debug print statement
2025-07-10 Start controller thread in HMIController and adjust speed parameters in EscapeElevatorThread; update timeout handling in ControllingScreen
2025-07-10 Update camera settings to HD2K resolution and 15 FPS; change saved image format to PNG
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2025-07-10 Reset disco_mode on transition to MAIN_SCREEN in HMIController
    [fsm2.py]
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2025-07-10 Reset disco_mode on transition to MAIN_SCREEN in HMIController; add debug prints in PathFollower for path tracking
    [fsm2.py]
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2025-07-10 Enhance lookahead point logic in PathFollower; implement direction reversal for looping paths and clean up debug prints
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2025-07-11 Fix command handling for restart functionality in HMIController
    [fsm2.py]
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2025-07-11 Fix controller initialization to explicitly pass config as a keyword argument
    [fsm2.py]
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2025-07-11 Fix frame corner indexing in crop_and_rotate_frame method
    [image_controller.py]
2025-07-11 Update Arduino angle correction offsets in config.yaml
    [config.yaml]
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2025-07-11 Fix pathfinding thread to handle ball position and pathfinding failures gracefully
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2025-07-14 Enhance pathfinding configuration by adding cache size and tolerance parameters, and update PathMemory initialization to use config values.
    [config.yaml, main.py]
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2025-07-14 Refactor README and remove unused files
    - Updated README.md to reflect the 2025 project details, including system overview, setup, and configuration.
    - Removed run_controller_RL.py as it was no longer needed for the current architecture.
    - Deleted kalmanfilter.py, which was not utilized in the project.
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2025-07-14 Fix model path in tracking configuration
    [config.yaml]
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2025-07-14 Fix horizontal control parameter assignment and update debug output
    [pos2.py]
2025-07-15 Fix array construction in waypoint logger condition
    [pos2.py]
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2025-07-15 Add stuck velocity threshold parameter to controller configuration
    [pos2.py]
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2025-07-15 Add upper position threshold for stuck detection in controller
    [config.yaml, pos2.py]
2025-07-15 Refactor stuck detection logic to include upper position threshold and apply wiggling for improved responsiveness
    [pos2.py]
2025-07-15 Add debug print statements for stuck detection thresholds
    [pos2.py]
2025-07-15 Refactor stuck detection logic to use overall distance for threshold checks
    [pos2.py]
2025-07-16 Add stuck time threshold to controller and implement timer logic for stuck detection
    [config.yaml, pos2.py]
2025-07-16 Initialize stuck detection flags for x and y axes in Controller class
    [pos2.py]
2025-07-16 Add stuck detection hold time for controller's x and y axes
    [config.yaml, pos2.py]
2025-07-16 Refactor stuck detection logic to use active flags for x and y axes
    [pos2.py]
2025-07-16 Update control logic to check active stuck flags before sending speed commands
    [pos2.py]
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2025-07-16 Fix import errors in HMIController and add utility_threads module for thread management
    [fsm2.py, utility_threads.py]
2025-07-16 Fix import typos for utility_threads in multiple files
    [run_controller_main.py]
2025-07-16 Add elevator state handling and fix import typo in utility_threads
    [fsm2.py, pos2.py, utility_threads.py]
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2025-07-16 La til 3d model filene, model så og si ferdig
    [20x20x220.SLDPRT, 20x20x285.SLDPRT, 20x20x85.SLDPRT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]
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2025-07-17 Fix variable assignments in sample_waypoints function for clarity and correctness
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2025-07-17 Fix elevator command to send 'up' signal instead of 'down' in HMIController
    [fsm2.py]
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2025-07-17 Refine integral reset conditions in Controller to account for stuck states
    [pos2.py]
2025-07-17 Add logging for integral reset conditions in PID controller
    [pos2.py]
2025-07-17 Comment out elevator state updates in HMIController and simplify integral reset conditions in Controller
    [fsm2.py, pos2.py, run_controller_main.py]
2025-07-18 Refactor and enhance functionality across multiple modules
    - Updated DiscoThread to improve hue initialization and ensured proper stopping mechanism.
    - Removed estimate_dynamics.py as it is no longer needed.
    - Cleaned up main.py by removing unnecessary comments and improving readability.
    - Introduced finite_state_machine.py to manage system states and transitions effectively.
    - Implemented mqtt_client.py for robust MQTT communication with error handling and command processing.
    - Developed position_controller.py to handle position and orientation control with PID tuning.
    - Added low_pass_filter.py for smoothing position updates in tracking.
    [finite_state_machine.py, image_controller.py, main.py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]
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2025-07-18 Update logging functionality and elevator state initialization
    - Refactor reward calculation in LoggingThread for improved clarity and performance.
    - Initialize elevator state to "down" in Controller for consistent behavior.
    - Correctly instantiate and start LoggingThread in main function.
    [position_controller.py, run_controller_main.py]
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2025-07-23 Fix button placement reference for Xbox button in main screen UI
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2025-07-23 Refactor controller interface: replace XboxController with JoystickController, update state management to HumanController, and implement new Human and Practice screens.
    [finite_state_machine.py, main.py]
2025-07-23 Enhance joystick control management in HMIController and improve error handling for background image in HumanScreen. Update button label in MainScreen for clarity.
    [finite_state_machine.py]
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2025-07-23 Fix input field initialization: move update_input_fields call to after button creation for proper layout.
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2025-07-23 Refactor PlayVsFriendScreen: replace player count dropdown with buttons for improved selection and update UI labels for clarity
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2025-07-24 Fix elevator timing logic and variable types in actuator control
    [actuator_control.ino]
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2025-07-24 Add leaderboard functionality: implement LeaderboardScreen and integrate with main app
    [leaderboard_maze1.csv]
2025-07-24 Refactor leaderboard functionality: update leaderboard directory path, add maze toggle button, and create leaderboard for Maze 2
    [leaderboard_maze1.csv, leaderboard_maze2.csv]
2025-07-24 Update leaderboard CSV files for Maze 1 and Maze 2 with new entries and improve leaderboard loading logic in LeaderboardScreen
    [leaderboard_maze1.csv, leaderboard_maze2.csv]
2025-07-24 Update leaderboard CSV files for Maze 1 and Maze 2 with new entries; change navigation to HumanScreen in LeaderboardScreen
    [leaderboard_maze1.csv, leaderboard_maze2.csv]
2025-07-24 Fix date format in leaderboard and adjust button positioning in PlayAloneScreen
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2025-07-24 Fix save path in OfflineLogger initialization to use default directory
    [run_controller_main.py]
2025-07-24 Fix current waypoint handling in LoggingThread; allow for integer indices and coordinate tuples
2025-07-24 Add vision utilities and threading for ball tracking and pathfinding
    - Implemented vision_utils.py for HSV color tracking and center of mass calculation.
    - Created utility_functions.py for path manipulation and elevator detection.
    - Developed utility_threads.py to manage threading for ball detection, pathfinding, and various control mechanisms (e.g., BlinkRed, DiscoThread).
    - Integrated pathfinding logic using A* algorithm with caching for efficiency.
    - Added functionality for dynamic color control and elevator management in response to detected conditions.
    [leaderboard_maze1.csv, leaderboard_maze2.csv]
2025-07-24 Fix import paths in image_controller.py for consistency
    [image_controller.py]
2025-07-24 Fix import path for run_controller_main to use the app namespace
    [finite_state_machine.py]
2025-07-24 Fix model path in tracking configuration to use the correct directory
    [config.yaml]
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2025-07-25 Enhance play alone mode: implement game result feedback and reset game state
    [finite_state_machine.py]
2025-07-25 Update game configuration: swap goal coordinates and adjust leaderboard folder path
    [config.yaml]
2025-07-25 Enhance player name handling: integrate MQTT subscription for player name and update game state accordingly; fix leaderboard CSV formatting and ensure proper newline handling; improve UI feedback for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
    [leaderboard_maze1.csv]
2025-07-25 Enhance Play Alone functionality: implement image buffer clearing, improve game state reset logic, and refine UI memory management
    [finite_state_machine.py]
2025-07-25 Refactor Play Alone restart logic: streamline image system reset, enhance tracking service restart, and improve thread management
    [finite_state_machine.py]
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2025-07-25 Update path cache file location in config.yaml to ensure correct file access
    [config.yaml]
2025-07-25 Refactor tracking system: replace HSV-based tracking with multi-modal methods, enhance template extraction and histogram matching for improved ball detection
    [config.yaml]
2025-07-25 Refactor tracking system: replace multi-modal tracking methods with HSV-based tracking, update configuration parameters for improved ball detection
    [config.yaml]
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2025-07-28 Enhance PlayVsAI error handling: update PID result handling to include failure reasons and adjust UI behavior based on pathfinding results
    [finite_state_machine.py]
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2025-07-28 Refactor controller parameters: increase stuck detection sensitivity and adjust position controller gains
    [config.yaml]
2025-07-28 Refactor controller parameters: adjust stuck detection settings and position controller gains
    [config.yaml]
2025-07-28 Refactor controller parameters: update position controller gains and tolerances
    [config.yaml]
2025-07-28 Lagde ny lett labyrint og endret den forge lette til mellom. La til ny heis
    [20mm_rett.3MF, 20mm_rett.SLDPRT, 30mm_rett.3MF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]
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2025-07-29 Lagde holder til skjermen
    [10.1inch HDMI.stp, 5_grader_adapter.ipt, Body1.3MF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]
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2025-07-30 La till transport_holder
    [heis.SLDASM, heis_holder.3MF, heis_stag.3MF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]
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2025-07-30 Lagde spenningsavlaster til skjerm kablene
    [midt_ramme.SLDASM, skjerm_deksel.SLDPRT, skjerm_stativ.SLDASM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]
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2025-07-31 Fikkset venstre bein så det ikke treffer skruene til strekkavlasteren
    [skjerm_bein_venstre.3MF, skjerm_bein_venstre.SLDPRT, skjerm_deksel.SLDPRT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]
2025-08-01 Ryddet og flyttet i 3D modell filene
    [heis.SLDASM, hull.3MF, hull.SLDPRT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]
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2025-08-04 Replace circle with rectangle for safe_mask drawing in PathFindingThread
    [utility_threads.py]
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2025-08-05 Add PlayAloneFailed state and UI screen for failure handling
    [finite_state_machine.py]
2025-08-05 Enhance human turn initiation in PlayVsAI by adding elevator command sequence and resetting image path
    [finite_state_machine.py]
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2025-08-06 Fix joystick controller playalone_wait handling and adjust button font sizes in Admin Tools and Main Screen for better UI consistency
    [finite_state_machine.py]
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2025-08-06 Reduce interval for ImAliveThread and adjust initial delay in alive_reciever; add debug print for alive message reception; fix maze_y calculation in PlayVsAIScreen.
    [main.py, utility_threads.py]
2025-08-07 Add reboot functionality to admin tools and HMI controller
    [finite_state_machine.py, main.py]
2025-08-07 Increase reverse speed in EscapeElevatorThread from 25 to 35
    [utility_threads.py]
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2025-08-08 Fix camera boundary coordinates in ball_tracker_zed.py
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2025-08-08 Add speed reset for controller on blinker trigger in main loop
    [run_controller_main.py]
2025-08-08 Add debug prints for velocity and stuck status in axis control
    [position_controller.py]
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2025-08-08 Adjust stuck detection thresholds for position control
    [position_controller.py]
2025-08-10 La til dokumentasjon for det elektriske og transport staget og koblings skjema for det elektriske
    [maze.kicad_pcb, maze.kicad_sch]
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2025-08-11 Fix project root path resolution in HMIController
    [finite_state_machine.py]
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2025-08-12 Fix threading issue in PLAYVSAI PID turn by moving thread start after controller stop
    [finite_state_machine.py]
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2025-08-13 Fix winner determination logic in run_playvsai_human_turn method
    [finite_state_machine.py]
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2025-08-14 Fix tracker initialization to prevent multiple starts and comment out tracker start in HMIController
    [finite_state_machine.py]
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
